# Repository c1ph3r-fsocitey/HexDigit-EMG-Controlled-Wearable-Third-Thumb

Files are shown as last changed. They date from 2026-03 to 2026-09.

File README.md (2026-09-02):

# HexDigit-EMG-Controlled-Wearable-Third-Thumb
---
## **The reason behind doing this project?**

The idea behind this project was to explore human augmentation using accessible hardware. I wanted to go beyond traditional robotics and build something that directly interfaces with the human body — where muscle intent translates into mechanical action in real time.

Instead of using buttons or switches, the goal was to use EMG (Electromyography) signals from the pectoral muscle to control a wearable robotic thumb. This creates a more natural and intuitive interaction, making the device feel like an extension of the body rather than an external tool.

Additionally, I wanted to challenge myself by combining multiple domains:

* Bio-signal processing
* Wearable electronics
* Soft robotics (TPU flexure design)
* Tendon-driven actuation

---
## Mechanical Assembly

The mechanical assembly of HexDigit, including the TPU thumb, tendon mechanism, servo spool, PTFE tubing, and mounting system.

HexDigit Mechanical Assembly (https://youtu.be/TaqYRTzNGGQ)

**▶️ Watch: [Mechanical Assembly Video](https://youtu.be/TaqYRTzNGGQ)**
---
## EMG Control & Electronics

A walkthrough of the electronics and EMG control system, including the BioAmp EXG Pill, Arduino, servo control, electrode placement, and muscle-controlled actuation.

HexDigit EMG Control and Electronics (https://youtu.be/Fo5W3X72WSA)

**▶️ Watch: [EMG Control & Electronics Video](https://youtu.be/Fo5W3X72WSA)**
---

## **Is it solving a real-life problem?**

Yes — the system demonstrates a low-cost approach to human augmentation and assistive technology.

Potential real-world applications include:

* Assistive devices for individuals with reduced hand mobility
* Prosthetic control systems using EMG signals
* Industrial assistance (third hand for holding tools/components)
* Rehabilitation and physiotherapy devices
* Human-machine interfaces for robotics and control systems

Even in its current form, the device acts as a functional “third hand,” capable of stabilizing objects like tools while the user performs other tasks.

---

## **Materials Required:**

* BioAmp EXG Pill (Upside Down Labs)
* Arduino Nano
* MG995 Servo Motor
* XY3606 Buck Converter
* 11.1V (3S) Li-ion Battery (with BMS)
* Nylon Fishing Line (0.6 mm, high tensile strength)
* PTFE Tube (for tendon routing)
* 3D Printed TPU Thumb (flexure-based design)
* Velcro Straps (50 mm) for mounting
* 1000µF Capacitor (for servo stability)
* Rocker Switch
* DC Connectors (Male/Female)
* Wires (20–22 AWG)
* Heat shrink, connectors, mounting hardware

---

## **Procedure:**

### **1. EMG Signal Acquisition**

* Electrodes were placed on the medial region of the pectoralis major for strong EMG signals.
* The BioAmp EXG Pill was used to capture and amplify the signal.
* EMG-only mode was enabled for cleaner readings.

---

### **2. Signal Processing and Control**

* The amplified EMG signal was read using the Arduino Nano (analog input).
* Envelope detection and filtering were applied in code.
* A threshold-based trigger system was implemented:

  * Muscle flex → thumb closes
  * Relax → thumb opens

---

### **3. Mechanical Design (Thumb)**

* The thumb was redesigned as a **single-piece TPU flexure structure**.
* This eliminated the need for rigid joints and rubber bands.
* The design allows natural curling toward the palm.

---

### **4. Tendon-Driven Actuation**

* Nylon fishing line was used as a tendon.
* A PTFE tube was used to guide the tendon and reduce friction.
* The tendon is routed from the thumb to the servo mounted on the forearm.

---

### **5. Actuator Module (Forearm Mount)**

* MG995 servo was mounted on a 3D-printed forearm bracket.
* A custom spool was designed to wind the tendon smoothly.
* Velcro straps were used for wearable mounting.

---

### **6. Power System**

* A 3S (11.1V) battery powers the system.
* XY3606 buck converter steps voltage down to ~5.5V.
* A capacitor stabilizes servo current spikes.

---

### **7. Integration and Testing**

* System was tested incrementally:

  * Servo control via serial
  * Tendon movement calibration
  * EMG signal tuning
* Final system achieved:

  * Instant response
  * No false triggers
  * Natural thumb movement

---

### **Demo Highlights:**

* Muscle-controlled thumb actuation
* Real-time response with no perceptible delay
* Ability to hold and stabilize tools (e.g., screwdriver)
* Natural curling motion toward the palm

tt2
tt1

https://github.com/user-attachments/assets/95314fa1-27f8-4b96-a416-c7dec5d9dda4

---

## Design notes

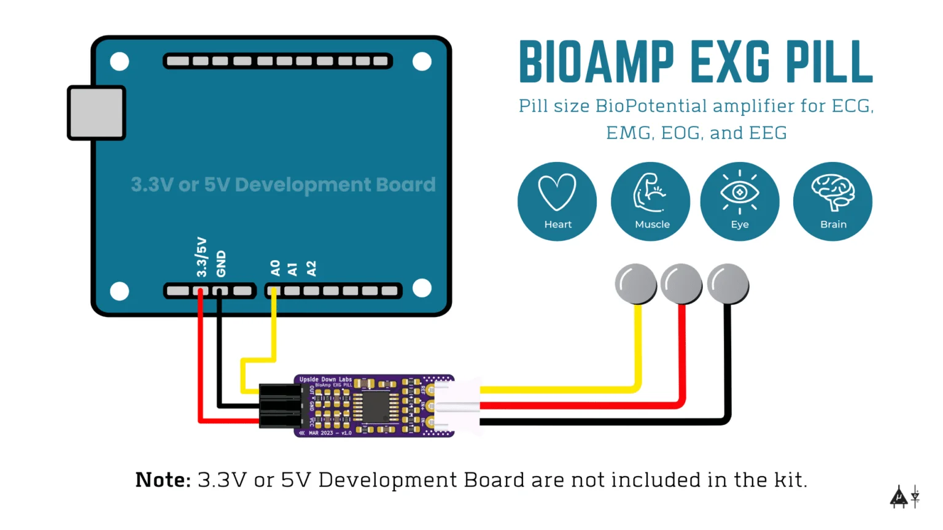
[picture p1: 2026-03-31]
image.png

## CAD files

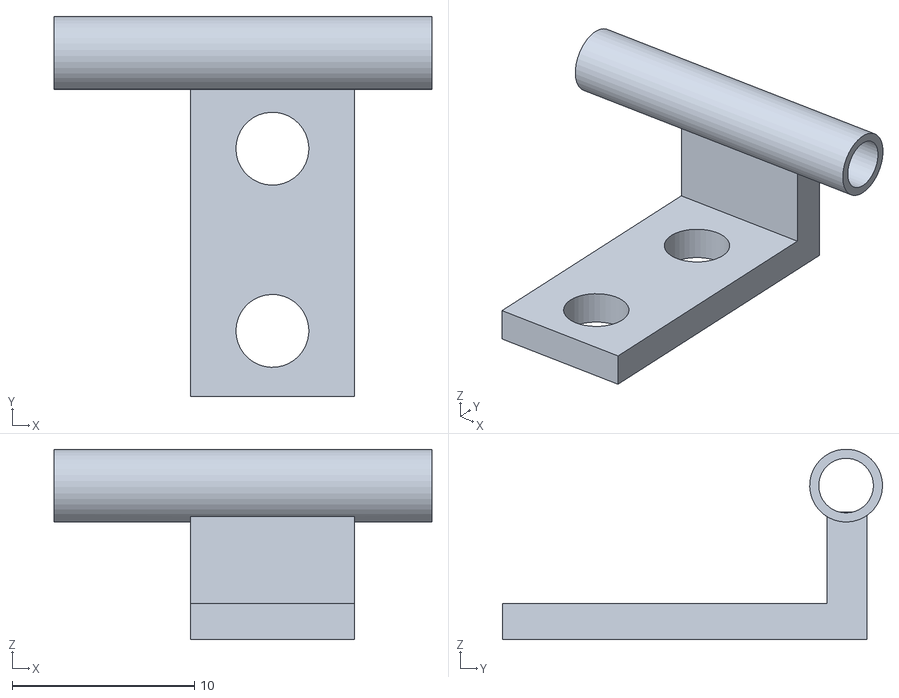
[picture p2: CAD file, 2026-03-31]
PTFE Guide.STL
20.7 x 20.9 x 10.5

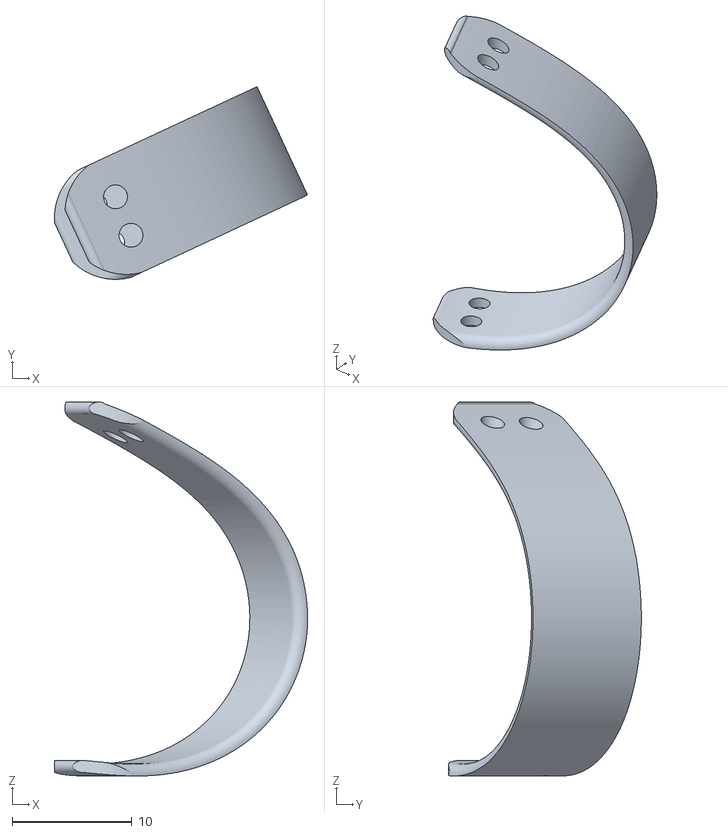
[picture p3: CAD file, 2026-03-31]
MountSupport1_V9.stl
21.2 x 16.1 x 31.3

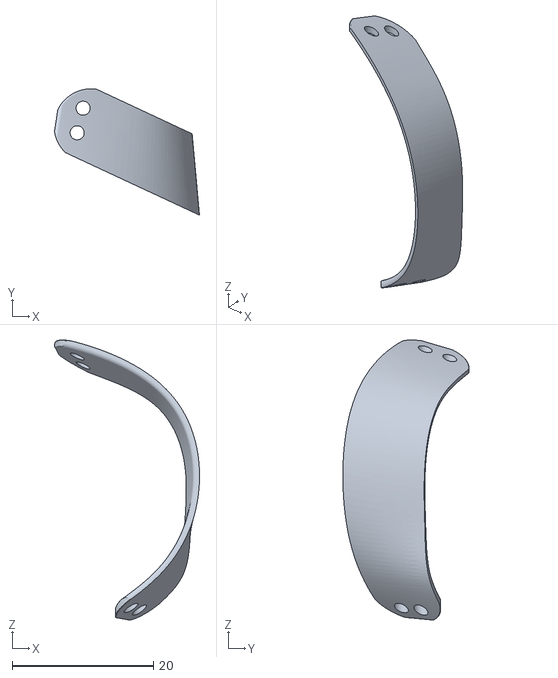
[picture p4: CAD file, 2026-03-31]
MountSupport2_V9.stl
20.5 x 17.9 x 39.7

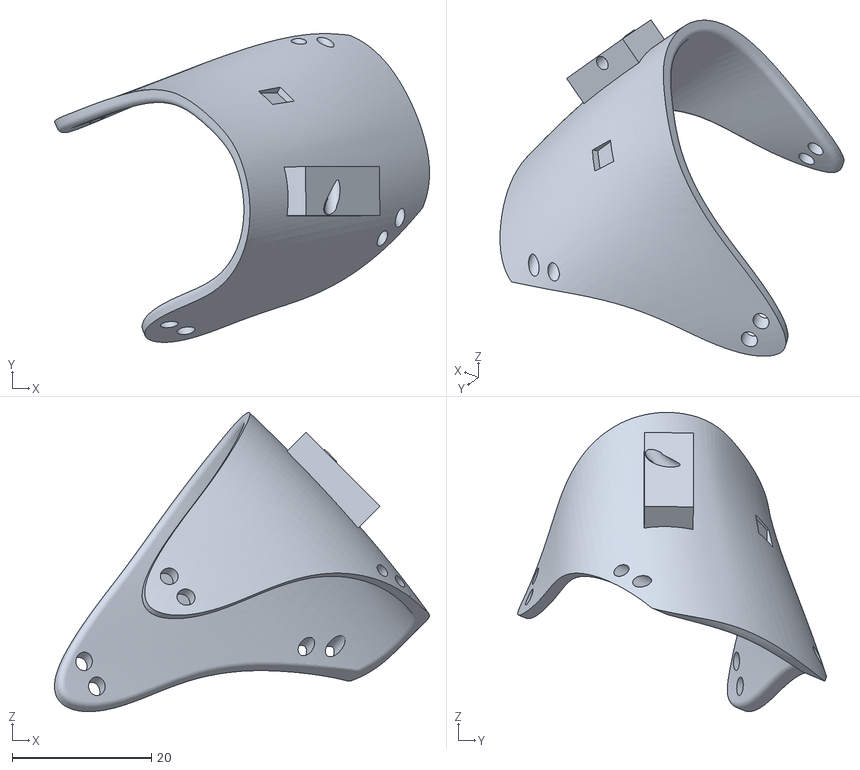
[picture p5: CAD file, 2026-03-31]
Mount_V9.stl
53.8 x 44.3 x 42.9

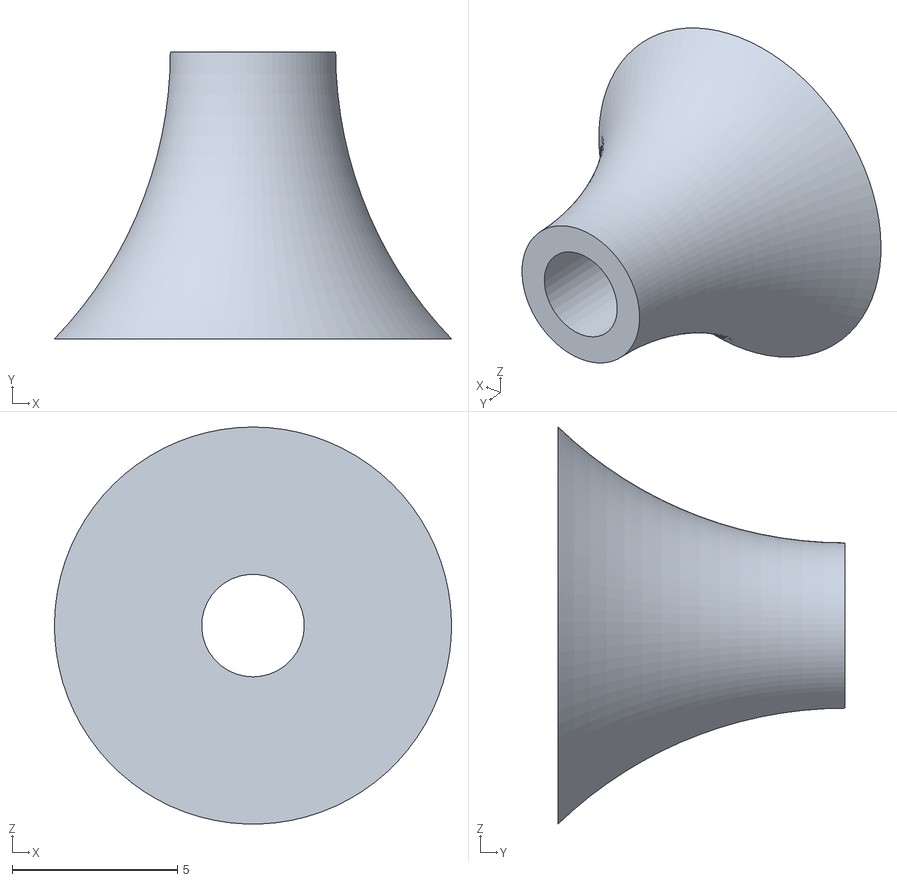
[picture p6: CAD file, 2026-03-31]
tube holder.STL
12.0 x 8.66 x 12.0

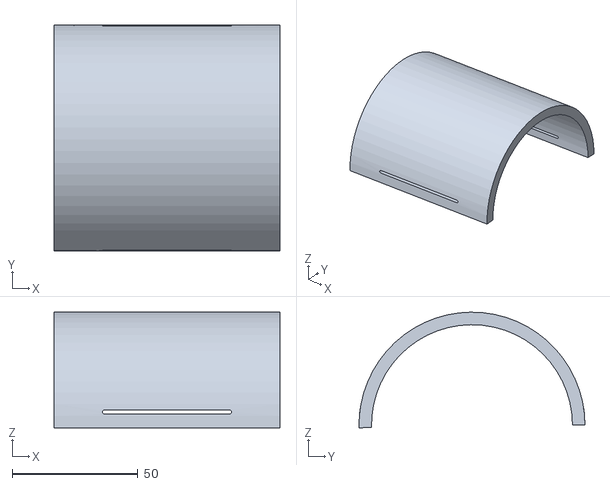
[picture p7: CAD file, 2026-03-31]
forearm_with_velcro_hole.STL
90.0 x 90.0 x 46.1

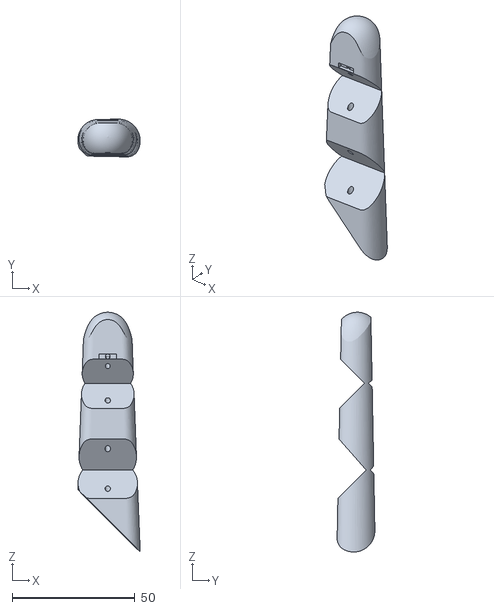
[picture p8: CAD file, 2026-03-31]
Finger_V9.stl
25.5 x 15.4 x 97.9

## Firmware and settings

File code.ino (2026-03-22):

#include <Servo.h>

#define SAMPLE_RATE 500
#define INPUT_PIN A5
#define SERVO_PIN 13
#define BUFFER_SIZE 128

#define THRESHOLD 12     // Adjust after testing
#define COOLDOWN 400     // ms

#define SERVO_OPEN 180
#define SERVO_CLOSE 30

int circular_buffer[BUFFER_SIZE];
int data_index = 0;
int sum = 0;

bool lastAbove = false;
bool closed = false;
unsigned long lastTrigger = 0;

Servo servo;

void setup() {
  Serial.begin(115200);
  servo.attach(SERVO_PIN);
  servo.write(SERVO_OPEN);
}

void loop() {
  static unsigned long past = 0;
  unsigned long present = micros();
  unsigned long interval = present - past;
  past = present;

  static long timer = 0;
  timer -= interval;

  if (timer < 0) {
    timer += 1000000 / SAMPLE_RATE;

    int raw = analogRead(INPUT_PIN);
    int filtered = EMGFilter(raw);
    int envelope = getEnvelope(abs(filtered));

    Serial.println(envelope);

    bool currentAbove = envelope > THRESHOLD;
    unsigned long now = millis();

    if (currentAbove && !lastAbove) {
      if (now - lastTrigger > COOLDOWN) {
        closed = !closed;
        servo.write(closed ? SERVO_CLOSE : SERVO_OPEN);
        lastTrigger = now;
      }
    }

    lastAbove = currentAbove;
  }
}

int getEnvelope(int abs_emg) {
  sum -= circular_buffer[data_index];
  sum += abs_emg;
  circular_buffer[data_index] = abs_emg;
  data_index = (data_index + 1) % BUFFER_SIZE;
  return (sum / BUFFER_SIZE) * 2;
}

float EMGFilter(float input) {
  float output = input;

  {
    static float z1, z2;
    float x = output - 0.05159732*z1 - 0.36347401*z2;
    output = 0.01856301*x + 0.03712602*z1 + 0.01856301*z2;
    z2 = z1;
    z1 = x;
  }
  {
    static float z1, z2;
    float x = output - -0.53945795*z1 - 0.39764934*z2;
    output = 1.00000000*x + -2.00000000*z1 + 1.00000000*z2;
    z2 = z1;
    z1 = x;
  }
  {
    static float z1, z2;
    float x = output - 0.47319594*z1 - 0.70744137*z2;
    output = 1.00000000*x + 2.00000000*z1 + 1.00000000*z2;
    z2 = z1;
    z1 = x;
  }
  {
    static float z1, z2;
    float x = output - -1.00211112*z1 - 0.74520226*z2;
    output = 1.00000000*x + -2.00000000*z1 + 1.00000000*z2;
    z2 = z1;
    z1 = x;
  }

  return output;
}

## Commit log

2026-03-22 Update README
    Expanded the README to include project motivation, real-life applications, required materials, and detailed procedures for EMG signal acquisition, processing, mechanical design, actuation, power syst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
2026-03-22 Add EMG servo control code in code.ino
2026-09-02 Update README with mechanical assembly and EMG control
    Added sections for mechanical assembly and EMG control with video links.
